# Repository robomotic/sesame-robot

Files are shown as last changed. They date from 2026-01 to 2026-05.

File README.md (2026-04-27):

# The Sesame Robot Project 
___







sesame-cover

<p align="center">
  <a href="https://www.youtube.com/watch?v=NIgoQVQF_Ng">
    tutorial-button
  </a>
  <a href="https://discord.gg/XDXkhQd8bC">
    discord-button
  </a>
</p>

___

**Greetings, from your new best friend.**

Sesame is an accessible Open-Source robotics project based on the ESP32 microcontroller system, with an emphasis on expression and movement. 
This project is designed for makers and engineers of all skill levels! Sesame offers a dynamic platform designed to start working with walking robots. 
To build a sesame robot, you will need basic soldering skills, $50-60 in hardware components, access to a 3D printer, and a basic understanding of Arduino IDE.

This repository contains the CAD design files, STL files, build and wiring guides, and the base/expanded firmware for the ESP32-based controller. 
There is also some included debugging firmware that may be helpful in getting your Sesame up and running.

## ⚡ Fork Notice: Leg & Foot Variations Specialist

**This is a specialized fork repository dedicated to developing and documenting different leg and foot variations for the Sesame robot.**

Explore alternative leg designs optimized for different locomotion characteristics and environmental conditions. All variations are 3D-printable and compatible with the standard Sesame platform. Find the STL files and assembly guides in `hardware/printing/`.

### Leg Variation Types

#### 1. Soft TPU Foot (Dampening)
A compliant, shock-absorbing foot design using flexible TPU material. Perfect for reducing impact forces and improving grip on smooth surfaces.

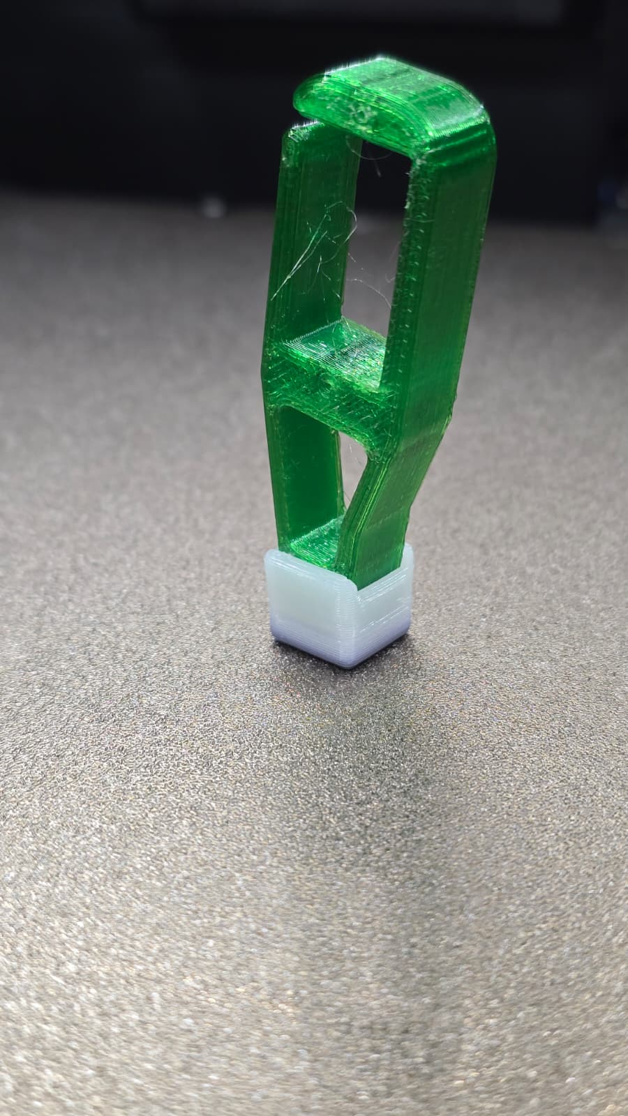
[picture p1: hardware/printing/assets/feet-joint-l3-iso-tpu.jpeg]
soft-tpu-foot


**Characteristics:**
- Excellent vibration dampening
- Enhanced grip on smooth surfaces
- Quieter operation
- Reduced stress on servo joints

#### 2. Shock Suspension with LEGO Integration
An advanced suspension system based on the LEGO 6.5L Soft Spring Grey component (Part #731c08). Provides spring-like shock absorption through mechanical linkage.

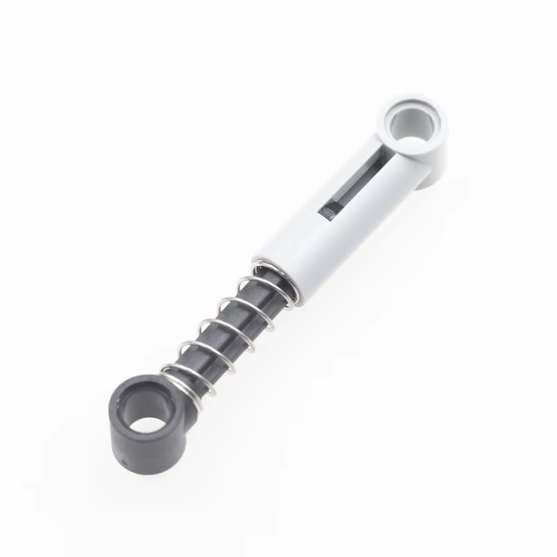
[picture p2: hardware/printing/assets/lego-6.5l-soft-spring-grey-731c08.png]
lego-6.5l-soft-spring


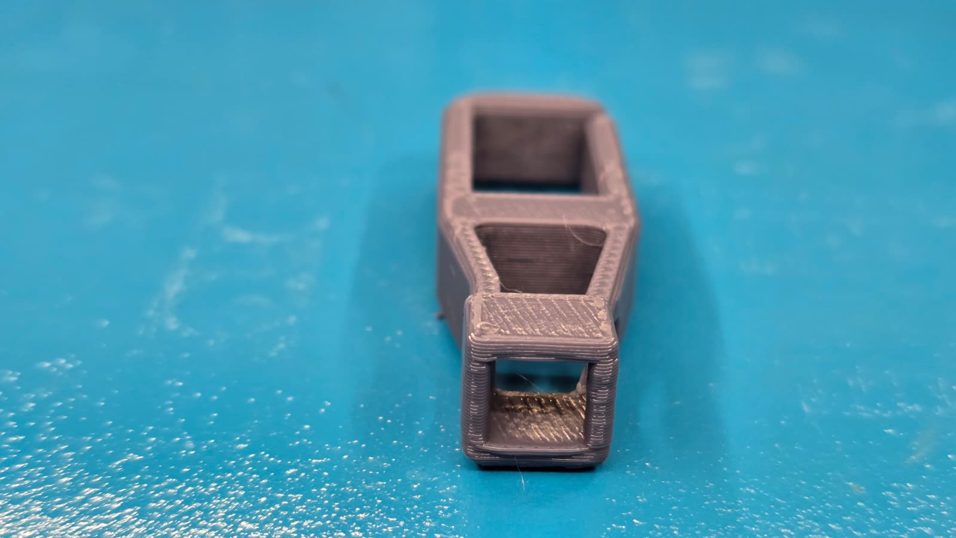
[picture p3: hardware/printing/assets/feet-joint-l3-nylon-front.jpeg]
lego-suspension


**Characteristics:**
- LEGO Part: 731c08 - 6.5L Soft Spring Grey
- Modular suspension design
- LEGO-compatible connectors
- Adjustable stiffness
- Superior obstacle traversal

#### 3. L4 Drilled Shock Harness (Experimental)
A modified version of the original L4 foot joint, drilled to accommodate the LEGO shock absorber spring. This design integrates the suspension directly into the foot structure.

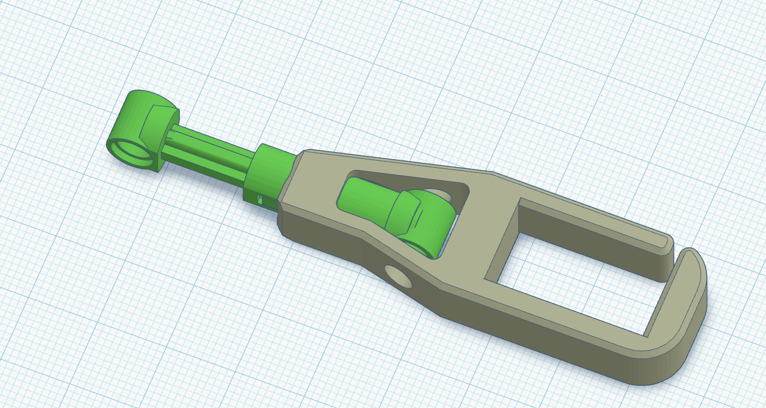
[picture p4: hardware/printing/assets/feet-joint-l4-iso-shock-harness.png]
l4-shock-harness


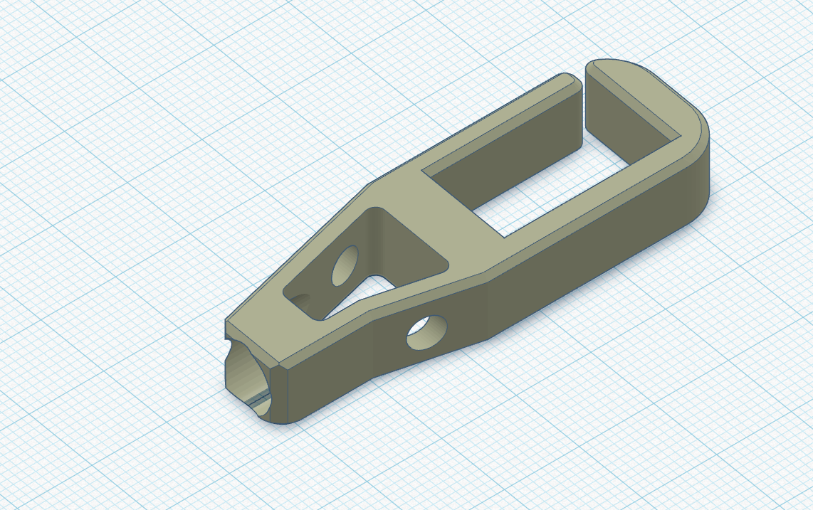
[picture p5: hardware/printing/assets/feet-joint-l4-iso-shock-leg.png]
l4-shock-leg


**Characteristics:**
- Based on original L4 foot joint design
- Direct LEGO spring integration
- More compact form factor
- ⚠️ **Note:** Bottom section requires structural reinforcement - design refinement in progress

---

## Features

*   **Quadruped Design:** Uses 8 servo motors (2 per leg) to achieve roughly 8 total degrees of freedom.
*   **Emotive Display:** Features a 128x64 OLED screen acting as a reactive face that syncs with movement.
*   **Fully Printable:** Designed entirely for 3D printing in PLA with minimal supports.
*   **Network Connectivity:** Connect to your WiFi network for remote control and API access.
*   **ESP-NOW Wireless:** Optional ESP-NOW firmware for sub-5ms latency, peer-to-peer control without WiFi (requires second ESP32 board).
*   **JSON API:** RESTful API for programmatic control from Python, JavaScript, and more.
*   **Conversational Faces:** Expressive emotion library with talk variants for voice assistant projects.
*   **Sesame Studio:** New animation composer software to easily create custom movements.
*   **Sesame Companion App:** Python application for voice control and advanced interactions.
*   **Serial CLI:** Control the robot and trigger animations via a Serial Command Line Interface or the web UI.
*   **Pre-programmed Emotes:** Includes animations for Walking, Waving, Dancing, Pointing, Resting, and more.

## Watch the launch video on YouTube

<a href="https://www.youtube.com/watch?v=1UDsWkcQZhc">thumb-youtube</a>

___

## Getting Started

Follow these steps to build your own Sesame Robot:

### 1. Gather Parts 
Check the **[Bill of Materials (BOM)](hardware/bom/README.md)** for a complete list of required electronics and hardware.
*   Microcontroller: Lolin S2 Mini (recommended for DIY builds), Sesame Distro Board V2 (included in Build Kits, pre-flashed), or ESP32-DevKitC-32E with Distro Board V1 (legacy)
*   Actuators: 8x MG90 Servos
*   Power: 5V 3A source (USB-C PD for S2 Mini and V2 Distro Board, or battery + buck converter; see BOM for the 2× 10440 Li-ion + 2× AAA holder option)

### 2. Print Parts 
Download the STLs and follow the **[Printing Guide](hardware/printing/README.md)**.
*   Designed for PLA
*   Minimal supports required

### 3. Build & Wire 
Follow the **[Build Guide](docs/build-guide/README.md)** and **[Wiring Guide](docs/wiring-guide/README.md)** to assemble the frame and connect the electronics.

### 4. Flash Firmware 
Upload the code from the **[Firmware Directory](firmware/README.md)**.
*   Requires Arduino IDE
*   Configure WiFi AP settings

#### Optional: ESP-NOW Low-Latency Firmware
For sub-5ms control via USB serial (no WiFi needed), flash the ESP-NOW variant instead:
1. Flash **Robot** with `firmware/sesame-firmware-espnow.ino` (ESP32-S3)
2. Flash **Controller** with `software/esp-now/ESP32_C3_Sesame/ESP32_C3_Sesame.ino` (ESP32-C3 Mini, plugged into your computer)
3. Set robot MAC in controller via serial: `SET_ROBOT_MAC <robot_mac>`
4. Send `PING` to verify connection
*See [ESP-NOW docs](software/esp-now/ESP32_C3_Sesame/README.md) for full details.*

### 5. Create Animations 
Use **[Sesame Studio](software/sesame-studio/README.md)** to visually design poses and sequences for your robot.

sesame-wakeup-gif

---

## Software & Firmware

### Sesame Studio
Sesame Studio is a standalone desktop application included in `software/sesame-studio/`. It allows you to:
*   Visually pose the robot using a schematic interface.
*   Generate C++ code for servo angles automatically.
*   Sequence frames into complex animations.

[**> Go to Sesame Studio**](software/sesame-studio/README.md)

### Sesame Simulator
The Sesame Simulator, created by Jay Li, is a Rust-based 3D simulation environment for testing Sesame's movements and kinematics in a virtual space. It features:
*   **Physics-based Simulation:** Test walking and balance without hardware.
*   **Web-based Interface:** Run the simulator directly in your browser.
*   **URDF Integration:** Accurate modeling of Sesame's physical properties.

[**> Go to Sesame Simulator**](https://one-for-all.github.io/sesame-robot-sim/)

### Sesame Companion App
The Sesame Companion App is a Python-based application that enables advanced control and interaction with your robot over your local network. It leverages the new JSON API and network mode features to provide:
*   **Voice Assistant Integration:** Control Sesame with voice commands and see real-time emotional expressions.
*   **Remote Control:** Command your robot from anywhere on your local network.
*   **Face Control:** Change expressions dynamically based on conversation or context.
*   **API Examples:** Reference implementation for building your own integrations.

The Companion App works with robots running the latest firmware with network mode enabled.

[**> Go to Sesame Companion App Repository**](https://github.com/dorianborian/sesame-companion-app)

### ESP-NOW Firmware (Low-Latency Wireless)

An alternative firmware that replaces WiFi-based control with ESP-NOW radio protocol for sub-5ms latency and simpler setup (no access point needed). Controlled via USB serial from any computer or Raspberry Pi.

*   **Extremely low latency** — 1-5 ms round trip vs 20-100 ms over HTTP
*   **No WiFi router needed** — peer-to-peer ESP-NOW radio link
*   **Universal control** — Python, Node.js, shell scripts, or any serial terminal
*   **Bidirectional** — send commands and query status, trims, config
*   **Reserved for future sensors** — protocol includes MPU6050 data slots

**Hardware:** ESP32-S3 (robot) + ESP32-C3 Mini (USB bridge)

[**> Go to ESP-NOW Documentation**](software/esp-now/ESP32_C3_Sesame/README.md)

[**> Quick Debug Reference**](software/esp-now/DEBUG_CHECKS.md)

### Firmware
The ESP32 firmware (`sesame-firmware-main.ino`) handles the kinematics, face display, and WiFi control interface.
*   **Web UI:** Control the robot from your phone via the built-in Access Point.
*   **Custom Faces:** Add your own bitmaps (guide in firmware docs).

[**> Go to Firmware Docs**](firmware/README.md)

---

## Contributing

This robot is a platform for building new features, cosmetics, tools, and ideas. Since the current firmware is a basic implementation, pull requests are very welcome for:
*   Kinematics improvements
*   New animations
*   Improved Web UI/UX
*   Sensor integration (Ultrasonic, Gyro, etc.)

I would also love to see forks of this project with new hardware, software, faces, etc. Be sure to send me a message if you end up building one, and I might feature you on my website or channel!
  
---

## Sesame Complete Build Kit Pre-orders available!
I am excited to announce that, after popular demand, Sesame Complete Build Kits are now available for pre-order! 

That's right, your little robot companion just got even easier to build. Each kit includes all the components you need to build a full Sesame Robot. With the included detailed instructions, guides, and resources, this kit is perfect for both seasoned Makers and beginners. Click the image below to learn more.

<a href="https://www.doriantodd.com/sesame/kit">kits-availible</a>

---

## Credits

A special thanks to **Jason** for his invaluable contributions to 3D printing and design optimization. His expertise and dedication have greatly enhanced the quality and manufacturability of the Sesame robot platform.

---

*Created by [Dorian Todd](https://www.doriantodd.com/). Need help with your Sesame Robot? Send me a message on Discord, my username is "starphee"*

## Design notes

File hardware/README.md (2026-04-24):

# Hardware

All mechanical and electrical source files for the Sesame Robot live here. The hardware stack supports multiple build paths:

- **Hand-wired / Lolin S2 Mini build** for simple protoboard construction (recommended for DIY builds).
- **Custom Sesame Distro Board V2 build** for a professional SMD design with PD and battery support (included in Sesame Build Kits, pre-flashed).
- **Custom Sesame Distro Board V1 build** (legacy) for ESP32-DevKitC-32E stackup (phased out but still supported).

Use the sections below to jump to the files that match the version you are assembling.

## Directory Guide

| Folder | What you will find |
| --- | --- |
| [bom](bom/README.md) | Full bill of materials covering both wiring approaches, plus power budget notes and links back to the build tutorial. Start here to gather every component before printing or soldering. |
| [cad](cad/README.md) | Parametric STEP and Fusion 360 source models for every printed part. Great for remixing joint geometry or adapting the shell—just note the caution about features that may not translate across CAD packages. |
| [pcb](pcb/README.md) | Sesame Distro Board V2 (current) and V1 (legacy) schematics, layout files, Gerber files, BOM, and Pick-and-Place files. Includes ordering instructions for PCBway fabrication and assembly services. |
| [printing](printing/README.md) | Practical PLA print settings, support callouts, and image references for joint orientation and the top cover’s manual supports. |

## Getting Started

1. **Decide on a wiring strategy.** Review the comparison section in [docs/wiring-guide/README.md](../docs/wiring-guide/README.md) to choose between the protoboard and custom PCB routes. The Lolin S2 Mini build is recommended for DIY builders. If you have a Sesame Build Kit, your V2 Distro Board is already pre-flashed and ready to use.
2. **Print the shell and joints.** Follow the presets in [printing/README.md](printing/README.md) to prep the 3D files from `hardware/printing/stl`.
3. **Source electronics.** Use the line-by-line list in [bom/README.md](bom/README.md) and verify your power supply meets the 5V/3A requirement.
4. **Assemble electronics.** Reference either the hand-wiring steps or the appropriate Distro Board guide plus the wiring diagrams in `docs/wiring-guide/`.

> [!TIP]
> Keep photos of your wiring progress. They are invaluable for troubleshooting later and help when sharing build notes with the community.

## Supporting Documents

- [docs/build-guide/README.md](../docs/build-guide/README.md) for end-to-end assembly sequencing.
- [docs/wiring-guide/README.md](../docs/wiring-guide/README.md) for wiring diagrams, safety notes, and packing tips.

Improvements, remixes, and test reports are welcome, file issues or PRs with any updates you discover while building. <3

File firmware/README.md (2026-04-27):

# Sesame Robot Firmware

This document provides technical information on the firmware architecture, control logic, and hardware abstraction layers used in the Sesame Robot.

>[!NOTE]
> The firmware is now organized into a modular structure with a main entry point and specialized header files for bitmaps, movement, and web assets. This makes customization much easier and the codebase cleaner.

## Table of Contents

- [How to Flash the Firmware](#how-to-flash-the-firmware)
- [Network Configuration](#network-configuration--connectivity)
- [API Reference](#api-reference)
  - [Legacy Web Endpoints](#legacy-web-endpoints)
    - [Servo Trims](#servo-trims)
  - [JSON API](#json-api-recommended-for-network-clients)
  - [Python Examples](#python-api-example)
  - [JavaScript Examples](#nodejsjavascript-example)
- [Advanced Integration Examples](#advanced-integration-examples)
  - [Voice Assistant Integration](#voice-assistant-integration)
  - [Home Automation](#home-automation-integration)
- [Servo Calibration & Trims](#servo-calibration--trims)
- [Idle Animation System](#idle-animation-system)
- [Firmware Architecture](#firmware-architecture)
- [Technical Implementation](#technical-implementation-overview)
- [Asset Pipeline & Face Customization](#asset-pipeline--face-customization)
- [Hardware Abstraction Layer](#hardware-abstraction-layer-hal)

## How to Flash the Firmware

> [!NOTE]
> **Sesame Build Kit Users:** Your Distro Board V2 comes pre-flashed with the latest firmware. You only need to flash firmware if you want to customize it or update to a newer version.

### Prerequisites
1. **Arduino IDE** (version 2.0 or higher recommended)
2. **ESP32 Board Support**: Install via Arduino IDE's Board Manager
   - Open Arduino IDE
   - Go to **File → Preferences**
   - Add to "Additional Board Manager URLs": `https://raw.githubusercontent.com/espressif/arduino-esp32/gh-pages/package_esp32_index.json`
   - Go to **Tools → Board → Boards Manager**
   - Search for "ESP32" and install "ESP32 by Espressif Systems" (v2.0.0 or higher)
3. **Required Libraries** (install via Library Manager):
  - `ESP32Servo` **v3.0.9** (recommended)
   - `Adafruit SSD1306`
   - `Adafruit GFX Library`

> [!IMPORTANT]
> Use **ESP32Servo v3.0.9** for this project. Newer releases currently have a known issue where writing to one servo can affect multiple channels ([madhephaestus/ESP32Servo#103](https://github.com/madhephaestus/ESP32Servo/issues/103)).

### Flashing Steps
1. **Connect your board** via USB to your computer
2. **Open the firmware**:
   - Open [sesame-firmware-main.ino](sesame-firmware-main.ino) in Arduino IDE
   - Make sure you have it in a folder with the same name.
   - Also include all of the .h header files.
3. **Select your board**:
   - Go to **Tools → Board**
   - For Lolin S2 Mini: Select "LOLIN S2 Mini"
   - For Sesame Distro Board V1: Select "ESP32 Dev Module"
   - For Sesame Distro Board V2: Select "ESP32S3 Dev Module"
4. **Configure board settings**:
   - **For Lolin S2 Mini**:
     - **Upload Speed**: 921600
     - **USB CDC On Boot**: "Enabled"
     - **Partition Scheme**: "Default 4MB with spiffs"
   - **For Distro Board V2 (ESP32-S3)**:
     - **USB CDC On Boot**: "Enabled" (Required for Serial Monitor)
     - **Flash Mode**: "QIO 80MHz"
     - **Partition Scheme**: "Default 4MB with spiffs"
5. **Select the correct port**:
   - Go to **Tools → Port** and select your ESP32's COM port
6. **Choose your board configuration** in the code:
   - Open [sesame-firmware-main.ino](sesame-firmware-main.ino)
   - Find the pin configuration section (around line 55-65)
   - **If you built with the Lolin S2 Mini:** Uncomment the S2 Mini `servoPins` array and `I2C_SDA`/`I2C_SCL` defines. Comment out the Distro Board section.
   - **If you built with the Distro Board V1 or V2 and ESP32-DevKitC-32E:** Uncomment the Distro Board `servoPins` array and `I2C_SDA`/`I2C_SCL` defines. Comment out the S2 Mini section. (V1 and V2 use the same pin configuration)
7. **(Optional) Configure network mode**:
   - If you want the robot to connect to your WiFi network (for API access and remote control), edit the network configuration section (around line 17-22):
   ```cpp
   #define NETWORK_SSID "YourNetworkName"  // Your WiFi network name
   #define NETWORK_PASS "YourPassword"     // Your WiFi password
   #define ENABLE_NETWORK_MODE true        // Set to true to enable
   ```
   - Leave `ENABLE_NETWORK_MODE false` to use Access Point mode only
8. **Upload the firmware**:
   - Click the **Upload** button (→) in Arduino IDE
   - Wait for compilation and upload to complete
9. **Test the connection**:
   - Open Serial Monitor (**Tools → Serial Monitor**, set baud rate to 115200)
   - Reset the board - you should see startup messages and network information
   - The serial monitor provides individual motor control for testing and troubleshooting
   - **If using AP mode only**: Connect to the "Sesame-Controller-BETA" WiFi network (password: `12345678`) and navigate to any website
   - **If using network mode**: Look for the "Connected to network!" message in Serial Monitor, then access via `http://sesame-robot.local` or the displayed IP address

### Troubleshooting
- **Linux USB Permissions**: If your port isn't showing up or you get "Permission Denied", you likely need to add your user to the `dialout` group: `sudo usermod -a -G dialout $USER`. Log out and back in for changes to take effect.
- **Upload fails**: Try holding the BOOT button while uploading, or try a different USB cable. For S3-based boards, the "USB CDC On Boot" setting is critical for finding the port after a reset.
- **Port not found**: Install the appropriate USB drivers (CP210x for S2 Mini, CH340 for some ESP32 boards). Windows 10/11 usually includes these.
- **Robot not moving**: Check power supply and servo connections; increase `motorCurrentDelay` in web settings if brownouts occur
- **Can't connect to network**: 
  - Verify `ENABLE_NETWORK_MODE` is set to `true` and SSID/password are correct
  - Check Serial Monitor for connection status - look for "Connected to network!" or error messages
  - Ensure your WiFi network is 2.4GHz (ESP32 does not support 5GHz)
  - Try increasing the connection timeout in the code (currently 10 seconds / 20 attempts)
- **mDNS hostname not resolving**:
  - On Windows, install [Bonjour Print Services](https://support.apple.com/kb/DL999)
  - On Linux, ensure `avahi-daemon` is installed and running
  - Try accessing via IP address instead (check Serial Monitor for the assigned IP)
  - Some routers block mDNS traffic - check router settings or use IP address
- **API commands not working**:
  - Ensure you're sending POST requests to `/api/command` (not GET)
  - Verify `Content-Type: application/json` header is set
  - Check Serial Monitor for error messages and parsed command output
  - Test with a simple cURL command first to verify connectivity

## Firmware Architecture

The firmware is split into several key files to keep the logic organized and assets easy to manage:

- **[sesame-firmware-main.ino](sesame-firmware-main.ino)**: The main entry point containing the `setup()`, `loop()`, core system logic, network configuration, and API endpoints.
- **[face-bitmaps.h](face-bitmaps.h)**: A dedicated header for OLED face macros and raw bitmap data. Now includes extensive conversational faces for voice assistant integration.
- **[movement-sequences.h](movement-sequences.h)**: Definitions for all procedural movement and pose animations.
- **[captive-portal.h](captive-portal.h)**: Contains the HTML, CSS, and JS for the web-based remote control interface.

## Servo Calibration & Trims

The firmware includes a built-in servo trim system to compensate for mechanical misalignment. This is essential because servo center positions may vary between units.

### Using the Web UI
1. **Access the Trims panel**: Open the web interface and tap **Trims** in the System section
2. **Adjust each servo**: Use the `+` and `-` buttons for each motor (L1-L4, R1-R4)
3. **Real-time feedback**: The robot moves immediately when you adjust a trim
4. **Visual indicators**: Green = positive offset, Red = negative offset, Theme color = zero
5. **Save**: Values are applied immediately; use "Save Trims" to confirm, or "Reset" to zero all values

### How Trims Work
- Trims are stored as `int8_t servoSubtrim[8]` offsets (degrees) applied to every servo command
- The firmware tracks each servo's target angle and re-applies all trims when any trim changes
- All poses, movements, and manual controls automatically include the trim offset
- Range: **-90 to +90 degrees** per servo

### NVS Persistence
The firmware can save trim values to ESP32 non-volatile storage (NVS):
```cpp
#define SAVE_TRIMS true  // Set to true to persist trims across reboots
```
When `SAVE_TRIMS` is `false` (default for testing), trims reset to zero on each boot. Set to `true` for production use.

### Serial CLI Commands
```
subtrim              - Display current trim values
subtrim <motor> <v>  - Set trim for motor 0-7 to value -90..+90
subtrim save         - Save trims to NVS
subtrim reset        - Zero all trims and save to NVS
```

## Technical Implementation Overview

The firmware is built on the Arduino-ESP32 framework. Currently the firmware is running on a single-core event loop, and hardware-based PWM timers for precise motor control.

### PWM & Servo Kinematics
- **Timer Allocation**: The firmware uses `ESP32PWM::allocateTimer(n)` to reserve hardware timers 0-3. This prevents conflicts with other peripherals and ensuring high-resolution PWM signals (50Hz frequency). Due to the limited number of timers, you may experience network errors upon adding additional devices or calls to the firmware. For example, in a modded version of the robot, I tried adding two ESCs and their servo controll to the code, and the CPU ran out of internal timers and caused the captive portal to die. If you are experiencing network errors with your custom firmware, check the timer allocation.
- **Pulse Width Mapping**: Leg servos are mapped from degrees (0-180) to microseconds (732us to 2929us). This range is set to the maximum travel on most hobby servos with a 180 degree limit, but can be edited in the `servos[i].attach()` calls. If you are using motors with a larger range of motion, like 270 degree servos, you need to set the PWM mapping to a different length of microseconds. For 270 degree servos specifically I found (833us to 2167us) works.
- **Staggered Activation**: To prevent VCC rail collapse (brownout) caused by simultaneous inductive loads, the `setServoAngle` helper introduces a mandatory `motorCurrentDelay` (default 20ms) between sequential pulses. This delay should be tweaked to your power setup. If you have a strong dedicated power supply you can try setting it to zero. It can also be changed while running through the AP controller settings menu.

### Communication & Networking Stack
- **Dual-Mode WiFi**: The ESP32 can simultaneously operate in both Access Point mode (for direct connections) and Station mode (connected to an existing network) using `WiFi.mode(WIFI_AP_STA)`.
- **SoftAP & Captive Portal**: The ESP32 initializes an Access Point using `WiFi.softAP()`. A `DNSServer` listens on UDP Port 53, using a wildcard "*" redirect to map all DNS queries to the internal gateway (`192.168.4.1`).
- **mDNS Service Discovery**: The firmware broadcasts `sesame-robot.local` via Multicast DNS (mDNS) using the `ESPmDNS` library, allowing network discovery without hardcoded IP addresses.
- **RESTful API Surface**: The `WebServer` handles both legacy URL-parameter endpoints and modern JSON-based API:
  - `/cmd?go=[dir]`: Legacy movement control
  - `/cmd?pose=[name]`: Legacy pose triggers
  - `/api/status`: JSON status endpoint (GET)
  - `/api/command`: JSON command endpoint (POST) - supports face-only updates and combined face+movement commands
  - `/getSettings` / `/setSettings`: Parameter configuration
  - `/getSubtrim` / `/setSubtrim` / `/resetSubtrim`: Servo subtrim management
- **Face-Only Command Support**: The `/api/command` endpoint intelligently detects face-only requests (no `command` field) and updates the display without triggering movement animations.
- **Non-Blocking Control Flow**: Instead of `delay()`, the firmware uses a custom `pressingCheck(String cmd, int ms)` function. This function polls `server.handleClient()` and `dnsServer.processNextRequest()` during animation frames, allowing for real-time interruptibility (e.g., immediate stop on button release). This pressingCheck protocol can be used for motion commands like walking to play each motion only when the button is held.

### Display & Graphics Subsystem
- **I2C Bus Hardware**: Utilizes the ESP32's hardware I2C controller at 400kHz (Fast Mode) for minimal latency when pushing full-frame buffers to the SSD1306 display.
- **Memory Management (`PROGMEM`)**: Large 128x64 bitmap arrays (1024 bytes per frame) are stored in Flash memory using the `PROGMEM` attribute.
- **Macro-Based Asset Management**: The firmware uses a `FACE_LIST` macro in [face-bitmaps.h](face-bitmaps.h) to automatically register and handle new faces, reducing the boilerplate required when adding animations.
- **Rendering Pipeline**: The `updateAnimatedFace()` function manages frame rates and sequence looping outside of the main movement logic to ensure smooth visual feedback even during complex movements.
- **Dynamic WiFi Info Overlay**: The `updateWifiInfoScroll()` function composites scrolling connection information over the face bitmap during the first 30 seconds of operation (before first input), drawing the face as background with a black bar and white text overlay for readability.
- **Idle Animation System**: Implements realistic idle behavior with randomized blinking (including double-blinks) and boomerang face animations, triggered automatically when no input is detected.

### Web Control Interface
The web interface ([captive-portal.h](captive-portal.h)) provides a responsive mobile-first controller:
- **Movement D-Pad**: Hold-to-move directional controls with immediate stop on release
- **Pose Grid**: One-tap pose triggers for animations (wave, dance, swim, etc.)
- **Manual Motor Control**: Per-servo angle sliders for fine positioning
- **Servo Trims**: Full-screen trim panel with +/- buttons for each servo (L1-L4, R1-R4)
  - Real-time servo movement on each trim adjustment
  - Values persist across reboots via ESP32 NVS (toggle with `#define SAVE_TRIMS`)
  - Trims are applied as offsets to all poses and movements automatically
  - Range: -90 to +90 degrees per servo
- **Gamepad Support**: Automatic detection and polling of USB/Bluetooth gamepads
- **Theme Customization**: Color picker with preset themes and custom color support

## Prerequisites & Development Environment

- **Board Support**: ESP32 by Espressif Systems (v2.0.0+ recommended). Lolin S2 Mini and ESP32-WROOM32 DevKitC are best supported.
- **Libraries**:
  - `ESP32Servo` **v3.0.9**: Low-level PWM timer management. (Pinned due to known multi-servo command leak in newer versions: [madhephaestus/ESP32Servo#103](https://github.com/madhephaestus/ESP32Servo/issues/103))
  - `Adafruit_SSD1306` & `Adafruit_GFX`: Buffer-based OLED rendering.
  - `ESPmDNS`: mDNS service discovery (included with ESP32 board support).
  - `DNSServer`: Captive portal DNS redirection (included with ESP32 board support).
  - `WebServer`: HTTP server implementation (included with ESP32 board support).
- **Tooling**: Arduino IDE 2.0+ recommended.

## Network Configuration & Connectivity

The firmware now supports **dual-mode WiFi operation**, allowing the robot to simultaneously act as an Access Point (for direct connections) and connect to your existing WiFi network (for integration with other devices and remote control).

### Access Point Mode (Default)
By default, the robot creates its own WiFi network:
- **SSID**: `Sesame-Controller-BETA`
- **Password**: `12345678` (Some devices may require you to change this if the default isn't connecting)
- **IP Address**: `192.168.4.1`

Connect to this network and navigate to any website to access the captive portal control interface. If you're having trouble connecting, try changing the password to something custom in the code's `#define AP_PASS` section.

### Network Mode (Optional)
To connect the robot to your home or office WiFi network:

1. **Enable Network Mode** in [sesame-firmware-main.ino](sesame-firmware-main.ino):
   ```cpp
   #define NETWORK_SSID "YourNetworkName"  // Your WiFi network name
   #define NETWORK_PASS "YourPassword"     // Your WiFi password
   #define ENABLE_NETWORK_MODE true        // Set to true to enable
   ```

2. **Flash the updated firmware** to your robot.

3. **Access via multiple methods**:
   - **mDNS Hostname**: `http://sesame-robot.local` (works on most devices)
   - **Network IP**: Check Serial Monitor at 115200 baud for the assigned IP address
   - **Still accessible via AP**: The robot maintains its Access Point even when connected to your network

### mDNS Discovery
The firmware includes an mDNS responder that broadcasts the hostname `sesame-robot.local` on your local network. This allows you to access the robot without knowing its IP address:

```bash
# Access from browser
http://sesame-robot.local

# Ping test
ping sesame-robot.local
```

**Note**: mDNS works natively on:
- macOS and iOS devices
- Linux with Avahi installed
- Windows 10+ (may require Bonjour service)

### Security Considerations

The firmware is designed for local network use and does not include authentication by default. When enabling network mode:

- **Local Network Only**: The robot responds to requests from any device on your network. Do not expose it to the internet without proper security measures.
- **No HTTPS**: Communication is unencrypted HTTP. Avoid transmitting sensitive data through the robot's API.
- **Access Point Password**: The default AP password is `12345678`. For production use, change `AP_PASS` in the firmware to a stronger password.
- **Trusted Networks**: Only connect your robot to trusted WiFi networks.

For enhanced security:
1. Change the default AP password to a strong, unique password
2. Use network segmentation (IoT VLAN) to isolate the robot from critical devices
3. Implement firewall rules to restrict access to specific IP addresses
4. Consider adding authentication headers in a custom firmware fork for production deployments

### WiFi Information Display
The robot's OLED screen now features an intelligent WiFi info system:
- **First 30 seconds**: If no input is received, WiFi connection information scrolls across the top of the display
- **After first input**: WiFi info disappears to show only faces
- **Dual-mode info**: When connected to both AP and network, displays both connection details

The scrolling text includes:
- Access Point SSID and IP
- Network name and IP (if connected)
- mDNS hostname
- Captive portal instructions

## API Reference

The firmware exposes both legacy web endpoints and a modern JSON-based API for programmatic control.

### Legacy Web Endpoints

These endpoints use URL parameters and are primarily used by the web interface:

#### Movement Control
```http
GET /cmd?go=forward
GET /cmd?go=backward
GET /cmd?go=left
GET /cmd?go=right
GET /cmd?stop
```

#### Pose Control
```http
GET /cmd?pose=wave
GET /cmd?pose=dance
GET /cmd?pose=rest
GET /cmd?pose=stand
# ... (see movement-sequences.h for all available poses)
```

#### Individual Motor Control
```http
GET /cmd?motor=1&value=90
# motor: 1-8 (motor number)
# value: 0-180 (angle in degrees)
```

#### Settings Management
```http
GET /getSettings
# Returns: {"frameDelay":100,"walkCycles":10,"motorCurrentDelay":20,"faceFps":8}

GET /setSettings?frameDelay=120&walkCycles=15&motorCurrentDelay=25&faceFps=10
```

#### Servo Trims
```http
GET /getSubtrim
# Returns: {"subtrim":[0,0,0,0,0,0,0,0]}

GET /setSubtrim?motor=1&value=5
# Sets servo 1 trim to +5 degrees (range: -90 to +90)

GET /resetSubtrim
# Resets all servo trims to 0
```

### JSON API (Recommended for Network Clients)

The JSON API is designed for programmatic control from external devices, Python scripts, and IoT integrations.

#### Get Robot Status
```http
GET /api/status
```

**Response:**
```json
{
  "currentCommand": "forward",
  "currentFace": "walk",
  "networkConnected": true,
  "apIP": "192.168.4.1",
  "networkIP": "192.168.1.100"
}
```

#### Send Commands
```http
POST /api/command
Content-Type: application/json

{
  "command": "forward",
  "face": "walk"
}
```

**Response:**
```json
{
  "status": "ok",
  "message": "Command executed"
}
```

#### Face-Only Updates
Send a face change without triggering movement:

```http
POST /api/command
Content-Type: application/json

{
  "face": "happy"
}
```

**Response:**
```json
{
  "status": "ok",
  "message": "Face updated"
}
```

#### Stop Command
```http
POST /api/command
Content-Type: application/json

{
  "command": "stop"
}
```

### Available Commands

**Movement Commands:**
- `forward`, `backward`, `left`, `right` - Continuous movement (loops until stopped)
- `stop` - Immediately stop current movement

**Pose Commands (one-shot animations):**
- `rest`, `stand`, `wave`, `dance`, `swim`, `point`
- `pushup`, `bow`, `cute`, `freaky`, `worm`, `shake`
- `shrug`, `dead`, `crab`

**Available Faces:**
- Movement faces: `walk`, `rest`, `stand`, `dance`, `wave`, etc.
- Conversational faces: `happy`, `sad`, `angry`, `surprised`, `sleepy`, `love`, `excited`, `confused`, `thinking`
- Talk variants: `talk_happy`, `talk_sad`, `talk_angry`, etc.
- Special: `idle`, `idle_blink`, `default`

### Python API Example

```python
import requests
import time

# Robot IP or hostname
robot_url = "http://sesame-robot.local"

# Get status
response = requests.get(f"{robot_url}/api/status")
status = response.json()
print(f"Current face: {status['currentFace']}")

# Make robot wave and show happy face
requests.post(f"{robot_url}/api/command", json={
    "command": "wave",
    "face": "happy"
})

time.sleep(3)

# Just change face without moving
requests.post(f"{robot_url}/api/command", json={
    "face": "excited"
})

# Stop movement
requests.post(f"{robot_url}/api/command", json={
    "command": "stop"
})
```

### cURL Examples

```bash
# Get robot status
curl http://sesame-robot.local/api/status

# Make robot dance
curl -X POST http://sesame-robot.local/api/command \
  -H "Content-Type: application/json" \
  -d '{"command":"dance","face":"dance"}'

# Change face only
curl -X POST http://sesame-robot.local/api/command \
  -H "Content-Type: application/json" \
  -d '{"face":"happy"}'

# Stop movement
curl -X POST http://sesame-robot.local/api/command \
  -H "Content-Type: application/json" \
  -d '{"command":"stop"}'
```

### Node.js/JavaScript Example

```javascript
const robotURL = 'http://sesame-robot.local';

// Get status
fetch(`${robotURL}/api/status`)
  .then(res => res.json())
  .then(data => console.log('Robot status:', data));

// Send command
fetch(`${robotURL}/api/command`, {
  method: 'POST',
  headers: {'Content-Type': 'application/json'},
  body: JSON.stringify({
    command: 'wave',
    face: 'happy'
  })
})
.then(res => res.json())
.then(data => console.log('Response:', data));

// Face-only update
fetch(`${robotURL}/api/command`, {
  method: 'POST',
  headers: {'Content-Type': 'application/json'},
  body: JSON.stringify({face: 'surprised'})
})
.then(res => res.json())
.then(data => console.log('Response:', data));
```

## Advanced Integration Examples

### Voice Assistant Integration

The combination of conversational faces, the JSON API, and network mode makes the Sesame Robot perfect for voice assistant projects. Here's an example using Python with speech recognition:

```python
import requests
import speech_recognition as sr
from textblob import TextBlob
import time

robot_url = "http://sesame-robot.local"

def analyze_sentiment(text):
    """Analyze sentiment and return appropriate face"""
    blob = TextBlob(text)
    polarity = blob.sentiment.polarity
    
    if polarity > 0.5:
        return "excited"
    elif polarity > 0.2:
        return "happy"
    elif polarity < -0.5:
        return "angry"
    elif polarity < -0.2:
        return "sad"
    else:
        return "thinking"

def set_robot_face(face, talking=False):
    """Update robot's face expression"""
    if talking:
        face = f"talk_{face}"
    
    requests.post(f"{robot_url}/api/command", json={"face": face})

# Initialize speech recognition
recognizer = sr.Recognizer()

while True:
    with sr.Microphone() as source:
        print("Listening...")
        set_robot_face("idle")
        
        try:
            audio = recognizer.listen(source, timeout=5)
            set_robot_face("thinking")
            
            text = recognizer.recognize_google(audio)
            print(f"You said: {text}")
            
            # Determine emotion and show talking face
            emotion = analyze_sentiment(text)
            set_robot_face(emotion, talking=True)
            
            # Process command...
            time.sleep(2)
            
            # Return to neutral
            set_robot_face(emotion, talking=False)
            
        except sr.WaitTimeoutError:
            set_robot_face("sleepy")
        except sr.UnknownValueError:
            set_robot_face("confused")
```

### Home Automation Integration

Integrate with Home Assistant or other home automation platforms:

```python
# Home Assistant automation example
import requests

def robot_notification(message_type):
    """Display robot emotion based on notification type"""
    robot_url = "http://sesame-robot.local"
    
    emotion_map = {
        "doorbell": "surprised",
        "alarm": "angry",
        "reminder": "thinking",
        "success": "happy",
        "error": "sad"
    }
    
    face = emotion_map.get(message_type, "default")
    requests.post(f"{robot_url}/api/command", json={"face": face})
    
    # Optional: add movement
    if message_type == "doorbell":
        requests.post(f"{robot_url}/api/command", json={
            "command": "wave",
            "face": "happy"
        })
```

### WebSocket Streaming (Advanced)

For real-time control with minimal latency, you can poll the status endpoint or implement a simple state machine:

```javascript
// React/Vue.js real-time robot control
class RobotController {
  constructor(robotURL) {
    this.url = robotURL;
    this.currentFace = 'default';
  }
  
  async updateEmotion(emotion, isSpeaking) {
    const face = isSpeaking ? `talk_${emotion}` : emotion;
    
    if (face !== this.currentFace) {
      await fetch(`${this.url}/api/command`, {
        method: 'POST',
        headers: {'Content-Type': 'application/json'},
        body: JSON.stringify({face})
      });
      
      this.currentFace = face;
    }
  }
  
  async getStatus() {
    const res = await fetch(`${this.url}/api/status`);
    return await res.json();
  }
  
  async performAction(action, emotion = null) {
    const payload = {command: action};
    if (emotion) payload.face = emotion;
    
    await fetch(`${this.url}/api/command`, {
      method: 'POST',
      headers: {'Content-Type': 'application/json'},
      body: JSON.stringify(payload)
    });
  }
}

// Usage
const robot = new RobotController('http://sesame-robot.local');

// Set emotion without moving
await robot.updateEmotion('happy', false);

// Set talking face
await robot.updateEmotion('excited', true);

// Perform action with face
await robot.performAction('dance', 'excited');

// Check status
const status = await robot.getStatus();
console.log(`Robot is ${status.currentFace} and doing ${status.currentCommand}`);
```

## Idle Animation System

The firmware includes an intelligent idle animation system that activates automatically:

### Behavior
- **Activation**: When the robot has received no commands for a period, it enters idle mode
- **Idle Face**: Displays a gentle "breathing" animation using the `idle` face in `FACE_ANIM_BOOMERANG` mode
- **Blinking**: Randomly triggers blink animations (3-7 second intervals)
- **Double Blinks**: 30% chance of a double blink for realistic behavior
- **Exit**: Any movement command or input immediately exits idle mode

### Technical Implementation
The idle system uses:
- `enterIdle()` - Activates idle face with boomerang animation
- `exitIdle()` - Returns to normal operation
- `updateIdleBlink()` - Manages random blink timing and double-blink logic
- `scheduleNextIdleBlink()` - Randomizes blink intervals for natural appearance

To customize idle behavior, modify the timing values in [sesame-firmware-main.ino](sesame-firmware-main.ino):
```cpp
scheduleNextIdleBlink(3000, 7000);  // Min and max ms between blinks
```

## Asset Pipeline & Face Customization

The firmware includes an intelligent idle animation system that activates automatically:

### Behavior
- **Activation**: When the robot has received no commands for a period, it enters idle mode
- **Idle Face**: Displays a gentle "breathing" animation using the `idle` face in `FACE_ANIM_BOOMERANG` mode
- **Blinking**: Randomly triggers blink animations (3-7 second intervals)
- **Double Blinks**: 30% chance of a double blink for realistic behavior
- **Exit**: Any movement command or input immediately exits idle mode

### Technical Implementation
The idle system uses:
- `enterIdle()` - Activates idle face with boomerang animation
- `exitIdle()` - Returns to normal operation
- `updateIdleBlink()` - Manages random blink timing and double-blink logic
- `scheduleNextIdleBlink()` - Randomizes blink intervals for natural appearance

To customize idle behavior, modify the timing values in [sesame-firmware-main.ino](sesame-firmware-main.ino):
```cpp
scheduleNextIdleBlink(3000, 7000);  // Min and max ms between blinks
```

## Hardware Abstraction Layer (HAL)

The firmware abstracts pin definitions via the `servoPins` array. The default configuration is optimized for the **Sesame Distro Board V1/V2** and **Lolin S2 Mini**, but is easily portable to any ESP32 with WiFi capability (e.g., S3, C3, or DevKit V1).

### Pin Configuration Tables

#### Lolin S2 Mini (ESP32-S2)

| Motor/Component | Array Index | GPIO Pin | Notes |
|---|---|---|---|
| Motor 0 | 0 | 1 | R1 |
| Motor 1 | 1 | 2 | R2 |
| Motor 2 | 2 | 4 | L1 |
| Motor 3 | 3 | 6 | L2 |
| Motor 4 | 4 | 8 | R4 |
| Motor 5 | 5 | 10 | R3 |
| Motor 6 | 6 | 13 | L3 |
| Motor 7 | 7 | 14 | L4 |
| **I2C SDA** | - | **33** | SSD1306 Data (Hardware I2C) |
| **I2C SCL** | - | **35** | SSD1306 Clock (Hardware I2C) |

#### Sesame Distro Board V1 & V2 (ESP32-WROOM32)

> [!NOTE]
> Both V1 and V2 Distro Boards use the same pin configuration.

| Motor/Component | Array Index | GPIO Pin | Notes |
|---|---|---|---|
| Motor 0 | 0 | 15 | R1 |
| Motor 1 | 1 | 2 | R2 |
| Motor 2 | 2 | 23 | L1 |
| Motor 3 | 3 | 19 | L2 |
| Motor 4 | 4 | 4 | R4 |
| Motor 5 | 5 | 16 | R3 |
| Motor 6 | 6 | 17 | L3 |
| Motor 7 | 7 | 18 | L4 |
| **I2C SDA** | - | **21** | SSD1306 Data (Hardware I2C) |
| **I2C SCL** | - | **22** | SSD1306 Clock (Hardware I2C) |

### Porting to Other ESP32 Variants

To port this to a different ESP32 variant, modify the `servoPins` and `I2C_` defines in the header of [sesame-firmware-main.ino](sesame-firmware-main.ino). Ensure the chosen pins are PWM-capable and not "input-only".

## Asset Pipeline & Face Customization

To maintain a clean main source file and optimize performance, face bitmaps are decoupled from the primary logic. Faces are managed in [face-bitmaps.h](face-bitmaps.h) using a "Single Source of Truth" macro system.

### Face Library

The firmware includes an extensive library of faces organized into three categories:

#### Movement Faces
Synchronized with physical poses and animations:
- `walk`, `rest`, `stand`, `swim`, `dance`, `wave`, `point`
- `pushup`, `bow`, `cute`, `freaky`, `worm`, `shake`, `shrug`
- `dead`, `crab`, `idle`, `idle_blink`

#### Conversational Faces
Designed for expressive communication and voice assistant integration:
- **Base emotions**: `happy`, `sad`, `angry`, `surprised`, `sleepy`, `love`, `excited`, `confused`, `thinking`
- **Talk variants**: `talk_happy`, `talk_sad`, `talk_angry`, `talk_surprised`, `talk_sleepy`, `talk_love`, `talk_excited`, `talk_confused`, `talk_thinking`

The "talk_" variants feature open mouths for lip-sync and animated speech. These faces are perfect for:
- Voice assistant projects (Alexa, Google Assistant, custom TTS)
- Chatbot interfaces controlled via the JSON API
- Interactive storytelling and educational applications
- Remote-controlled performances

#### Special Faces
- `default` - The startup/fallback face
- `idle` - Gentle breathing animation for idle state
- `idle_blink` - Blink animation triggered randomly during idle

### Adding Custom Faces

### Workflow:
1.  **Image Creation**: Find faces using Kaomoji or [Emojicombos](https://emojicombos.com/kaomoji). Create a `128x64` image in a tool like [jsPaint](https://jspaint.app/).
2.  **Bitmap Conversion**: Use [image2cpp](https://javl.github.io/image2cpp/) with `Horizontal` scaling, `128x64` resolution, and `Arduino Code` output.
3.  **Registration**:
    -   Add your face name to the `FACE_LIST` macro in [face-bitmaps.h](face-bitmaps.h).
    -   Paste the generated C array into [face-bitmaps.h](face-bitmaps.h) right after the last bitmap in the list.
    -   (Optional) For animations, add numbered suffixes (e.g., `_1`, `_2`) and register the FPS in the `faceFpsEntries` in [sesame-firmware-main.ino](sesame-firmware-main.ino).

### Animating Faces
For an animation to be recognized by the `MAKE_FACE_FRAMES` macro, your array names in [face-bitmaps.h](face-bitmaps.h) must follow a strict naming convention:
- **Root Frame**: `epd_bitmap_myface` (This is required and acts as frame 0).
- **Subsequent Frames**: `epd_bitmap_myface_1`, `epd_bitmap_myface_2`, etc.
- **Limit**: The default system supports up to 6 frames per face (Root + 5 numbered frames).
- **Animation Modes**: Animations can be configured to play as a `LOOP` (restarts at frame 0), `ONCE` (stops on the final frame), or `BOOMERANG` (plays forward then reverses). These modes are typically defined in [movement-sequences.h](movement-sequences.h) when triggerring a pose.

### Macro System
The `FACE_LIST` macro uses X-Macros to automatically generate variable declarations and registration objects:
```cpp
#define FACE_LIST \
    X(walk) \
    X(rest) \
    X(my_new_face) // Just add this line!
```
This eliminates the need to manually update multiple switch statements or arrays when adding new assets.

## Execution & Deployment

1.  **Toolchain**: Configure your IDE for `ESP32 Dev Module` or `Lolin S2 Mini`.
2.  **Calibration**: Use the Serial Monitor (115200) to send manual step commands (e.g., `rn wf`).
3.  **Power Management**: If the robot brownouts during movement, increase `motorCurrentDelay` in the web settings to further stagger servo bursts.

## ESP-NOW Firmware (Low-Latency Wireless)

An alternative firmware variant that replaces WiFi-based HTTP control with direct ESP-NOW radio communication. This version achieves sub-5ms latency and eliminates the need for an access point or WiFi router.

### Why Switch to ESP-NOW?

| Feature | WiFi Firmware (`sesame-firmware-main.ino`) | ESP-NOW Firmware (`sesame-firmware-espnow.ino`) |
|---|---|---|
| Control method | WiFi AP + HTTP server | ESP-NOW radio binary protocol |
| Latency | 20–100 ms (HTTP overhead) | 1–5 ms round-trip |
| Network setup | Requires AP connection, captive portal | Peer-to-peer, zero configuration |
| Interface | Web UI on phone/laptop | Serial/USB from computer or Raspberry Pi |
| Power consumption | Higher (WiFi AP active) | Lower (radio only when transmitting) |
| Reliability | TCP/IP stack, reconnection delays | Simple UDP-like packets, immediate |
| Sensor data streaming | Polling via HTTP requests | Can push sensor data asynchronously (future) |

### Hardware Setup

**You need two ESP32 boards:**
1. **Robot:** ESP32-S3 with Sesame Distro Board (flashed with `sesame-firmware-espnow.ino`)
2. **Controller:** ESP32-C3 Mini (flashed with `ESP32_C3_Sesame.ino`) connected to your computer via USB

The two boards communicate wirelessly — no wiring needed. The controller acts as a USB serial bridge, converting text commands from your computer into ESP-NOW binary packets for the robot.

### Getting Started

#### 1. Flash the Robot (ESP32-S3)

1. Open `firmware/sesame-firmware-espnow.ino` in Arduino IDE
2. Board: **ESP32S3 Dev Module**
3. Install libraries: `ESP32Servo` v3.0.9, `Adafruit SSD1306`, `Adafruit GFX`
4. Upload
5. Open Serial Monitor (115200 baud) and copy the MAC address:
   ```
   === Sesame Robot (ESP-NOW) ===
   MAC Address: DC:54:75:C8:43:00
   ```

#### 2. Flash the Controller (ESP32-C3 Mini)

1. Open `software/esp-now/ESP32_C3_Sesame/ESP32_C3_Sesame.ino` in Arduino IDE
2. Board: **ESP32C3 Dev Module**
3. Upload
4. Serial Monitor at 115200 baud
5. Tell the controller the robot's MAC:
   ```
   SET_ROBOT_MAC DC:54:75:C8:43:00
   ```
   This is saved to flash — run it once.

#### 3. Test

```
PING
```
Should respond:
```
PONG rtt=1.23ms
```

```
CMD wave
```
Robot waves.

**That's it.** Full command reference: `software/esp-now/ESP32_C3_Sesame/README.md`

### WiFi Channel Configuration

Both boards must use the same ESP-NOW channel (1–13). Default is channel 1.

**To avoid interference with your WiFi router:**
- If router uses channel 1 → set ESP-NOW to 6 or 11
- If router uses channel 6 → set ESP-NOW to 1 or 11
- If router uses channel 11 → set ESP-NOW to 1 or 6

On controller: `CHANNEL 6` (persisted)
On robot: change `#define ESPNOW_CHANNEL` in `espnow-protocol.h` and reflash.

Use the `WiFi_Channel_Scanner` sketch to find clear channels.

### Protocol Overview

Messages are binary structs over ESP-NOW. Controller ↔ Computer uses newline-terminated text. See `software/esp-now/espnow-protocol.h` for all struct definitions.

```
Computer           Controller (ESP32-C3)           Robot (ESP32-S3)
────────           ────────────────────           ─────────────────
"CMD wave\n"  ──→  parse  ──→  sesame_motion_cmd_t  ──→  onEspNowRecv()
                            {msg_type=0x01,           ↓
                             command="wave"}      ──→  currentCommand="wave"
                                                      runWavePose()
                                              ──→  send ACK
                                                        ↓
"OK\n"         ◄──  (ACK received)  ◄────────────────
```

### Serial Command Reference

Connect to the controller's USB serial port at **115200 baud**:

#### Motions
```
CMD forward   CMD backward   CMD left   CMD right
CMD rest      CMD stand      CMD wave   CMD dance
CMD swim      CMD point      CMD pushup CMD bow
CMD cute      CMD freaky     CMD worm   CMD shake
CMD shrug     CMD dead       CMD crab
STOP
```

#### Faces
```
FACE happy      FACE sad        FACE angry     FACE surprised
FACE sleepy     FACE love       FACE excited   FACE confused
FACE thinking   FACE idle       FACE default   FACE talk_happy
FACE talk_sad   ... (all talk_* variants)
```

#### Servos
```
SERVO 0 135           → Set motor R1 to 135°
SERVO_ALL 90          → All motors to 90°
```
Channels: 0=R1 1=R2 2=L1 3=L2 4=R4 5=R3 6=L3 7=L4

#### Trims
```
TRIM_SET 0 5          → +5° offset on motor R1
TRIM_GET              → Print all 8 trims
TRIM_RESET            → Zero all trims and save
```

#### Configuration
```
CONFIG_SET frameDelay 120
CONFIG_SET walkCycles 15
CONFIG_SET motorCurrentDelay 60
CONFIG_SET faceFps 12
CONFIG_GET
```

#### System
```
STATUS       → cmd=<current> face=<current>
PING         → PONG rtt=<ms>
MAC          → Show controller's MAC
CHANNEL      → Show current channel
CHANNEL 6    → Change channel (restart required)
SET_ROBOT_MAC DC:54:75:C8:43:00 → Persist robot MAC
HELP         → Show full help
```

### Python Control Example

```python
import serial, time

ser = serial.Serial('/dev/ttyUSB0', 115200, timeout=1)
time.sleep(2)

def cmd(c):
    ser.write(f"{c}\n".encode())
    time.sleep(0.1)
    print(ser.read_all().decode())

cmd("PING")
cmd("CMD wave")
cmd("FACE happy")
cmd("TRIM_GET")
ser.close()
```

### Serial Debug on the Robot

The robot's serial port has a full CLI that works alongside ESP-NOW:

```
help                → Show all debug commands
mac                 → Print robot MAC + channel
rn wf               → Walk forward
rn st               → Stand pose
0 90                → Set motor 0 to 90°
all 90              → Set all motors to 90°
subtrim             → List trim values
st 3 10             → Set motor 3 trim +10°
settings reset      → Reset to defaults
```

See `software/esp-now/DEBUG_CHECKS.md` for the full troubleshooting guide.

### Files

| File | Description |
|---|---|
| `firmware/sesame-firmware-espnow.ino` | Robot firmware, ESP-NOW receiver (ESP32-S3) |
| `software/esp-now/ESP32_C3_Sesame/ESP32_C3_Sesame.ino` | Controller firmware (ESP32-C3) |
| `software/esp-now/espnow-protocol.h` | Shared binary protocol header |
| `software/esp-now/DEBUG_CHECKS.md` | Quick debug reference |

### Troubleshooting Quick Table

| Symptom | Likely Cause | Fix |
|---|---|-----|
| `PING` times out | Robot MAC unknown to controller | `SET_ROBOT_MAC <robot_mac>` |
| No command response | Channel mismatch | Ensure both use `ESPNOW_CHANNEL` = same value |
| Latency >20 ms | Far apart / interference | Move closer; use channel 6/11; scan with WiFi scanner |
| Controller says "peer not registered" | Robot never received first packet | Send `PING`; check robot log for auto-registration |
| Servo jitter | `motorCurrentDelay` too low | `CONFIG_SET motorCurrentDelay 80` |

Full debug reference: `software/esp-now/DEBUG_CHECKS.md`

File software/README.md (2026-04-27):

# Software

Software applications for making the most of your Sesame Robot.

## Tools

### [Sesame Studio](sesame-studio/)
A visual Python-based tool for creating animations.

- **Graphical Interface**: layout joints on screen with guides.
- **Code Generator**: outputs C++ code ready for firmware.

[Go to Sesame Studio Documentation ->](sesame-studio/README.md)

### ESP-NOW Controller (`esp-now/`)
Lightweight wireless control using ESP-NOW (no WiFi router needed). An ESP32-C3 Mini connects via USB to your computer and bridges serial commands to the robot over ESP-NOW radio.

- **Low latency**: 1-5 ms round-trip vs 20-100ms over HTTP
- **No network setup**: Peer-to-peer, no access point required
- **Simple protocol**: Text commands over serial (easy from Python, shell, Node.js)
- **Full feature parity**: motions, faces, servo trim, configuration

**Components:**
- `espnow-protocol.h` — shared binary protocol header
- `ESP32_C3_Sesame/` — controller firmware (ESP32-C3)
- `sesame-firmware-espnow.ino` — robot firmware (ESP32-S3)

[Go to ESP-NOW Documentation ->](esp-now/ESP32_C3_Sesame/README.md)

[ESP-NOW Quick Debug Checks ->](esp-now/DEBUG_CHECKS.md)

### Sesame Companion App
A Python application for advanced robot control and interaction over your local network.

- **Voice Control**: Integrate with speech recognition for voice commands.
- **Emotion Mapping**: Automatically set robot expressions based on sentiment analysis.
- **Remote API Control**: Send commands and face changes via the JSON API.
- **Network Mode**: Requires robot firmware with network mode enabled.
- **Home Automation**: Example integrations with Home Assistant and other platforms.

**Note:** The Companion App is a separate repository and requires the latest firmware with network mode enabled.

[Go to Sesame Companion App Repository ->](https://github.com/dorianborian/sesame-companion-app)

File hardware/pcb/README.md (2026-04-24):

# PCB Schematics

Electronic schematics and PCB designs for the Sesame Robot Project. There are two versions of the Sesame Distro Board available: V2 (current) and V1 (legacy).

> [!NOTE]
> **For Sesame Build Kits:** All Sesame Build Kits include a pre-flashed Sesame Distro Board V2, so you don't need to order or assemble a board separately.

> [!TIP]
> **Building from Scratch?** If you're building a Sesame Robot from scratch, we recommend using the **S2 Mini with hand wiring approach** for the easiest assembly experience. The V2 distro board uses advanced SMD components that require specialized soldering skills or PCB assembly services.

---

## Sesame Distro Board V2 (Current)

The **Sesame Distro Board V2** is the latest version and features:
- **Power Delivery (PD) support** - Works with USB-C PD power supplies
- **Battery power support** - Also works with battery power
- **Compact SMD design** - All surface-mount components for a professional finish
- **Included in all Sesame Build Kits** - Pre-flashed and ready to use

### Assembly Options for V2

The V2 board consists entirely of SMD (surface-mount) components, which are **advanced to hand solder**. We recommend:

1. **PCB Assembly Service (Recommended):** Use [PCBway's PCB assembly service](https://www.pcbway.com/pcb-assembly.html) to have the board professionally assembled. Upload the Gerber, BOM, and Pick-and-Place files to their assembly service.
2. **Hand Soldering (Advanced Only):** Only attempt hand soldering if you're experienced with SMD components and have the proper tools (hot air station, fine-tip soldering iron, flux, etc.).

### V2 Files Available

All files are located in the [`distro-v2/`](distro-v2/) directory:
- **Schematic source:** `SCH_Sesame-Distro-Board-V2_2026-03-06.json` - EasyEDA source design file for the V2 schematic
- **Gerber file:** `Gerber_Sesame-Distro-V2_PCB.zip` - For PCB fabrication
- **BOM file:** `BOM_Sesame-Distro-V2.csv` - Bill of materials for SMD components
- **Pick-and-Place file:** `PickAndPlace_PCB_Sesame-Distro-V2.csv` - Component placement data for assembly

### PCBway / JLCPCB Sourcing Notes

When uploading the BOM to PCBway or JLCPCB for assembly, note the following three components that require special handling:

| Designator | Issue | Corrected Part | LCSC # |
|---|---|---|---|
| `U5`, `U7` | **Solder Pads** — these are copper pads only, no physical component is needed. Remove these lines from the BOM when ordering assembly. | N/A | N/A |
| `5-12V` | 2-pin 3.5 mm screw terminal. Original part `1984617` (Phoenix Contact) cannot be sourced. | `XY302V-3.5-2P` | [C784940](https://www.lcsc.com/product-detail/C784940.html) |
| `JST-XH` | 4-pin JST XH connector. Original `JST-XH-4-PIN` cannot be sourced. | `B4B-XH-A(LF)(SN)` | [C144395](https://www.lcsc.com/product-detail/C144395.html) |

The BOM CSV has already been updated with the corrected parts. The solder-pad rows are marked **"No Part Required"** in the Name field so they are easy to identify and exclude.

---

## Sesame Distro Board V1 (Legacy)

> [!CAUTION]  
> The Sesame Distro Board V1 is now **phased out** but still supported. V1 has some limitations: it won't run on tethered power (e.g., USB-C) and is harder to assemble than other options. V1 is still supported with wiring guides and firmware and works on battery power. If you have a V1 board, you can still use it successfully.

The Distro Board V1 pairs with the ESP32-DevKitC-32E.

> [!IMPORTANT]
> **ESP32 Pin Header Requirement:** The distro board V1 stacks on top of the ESP32-DevKitC-32E, so you need an ESP32 board **without pre-soldered pin headers**. If your board came with headers already soldered on the top, you will need to desolder all of the headers and flip them to the bottom side of the ESP32 board so the distro board can mount on top.

### V1 Board Schematic:

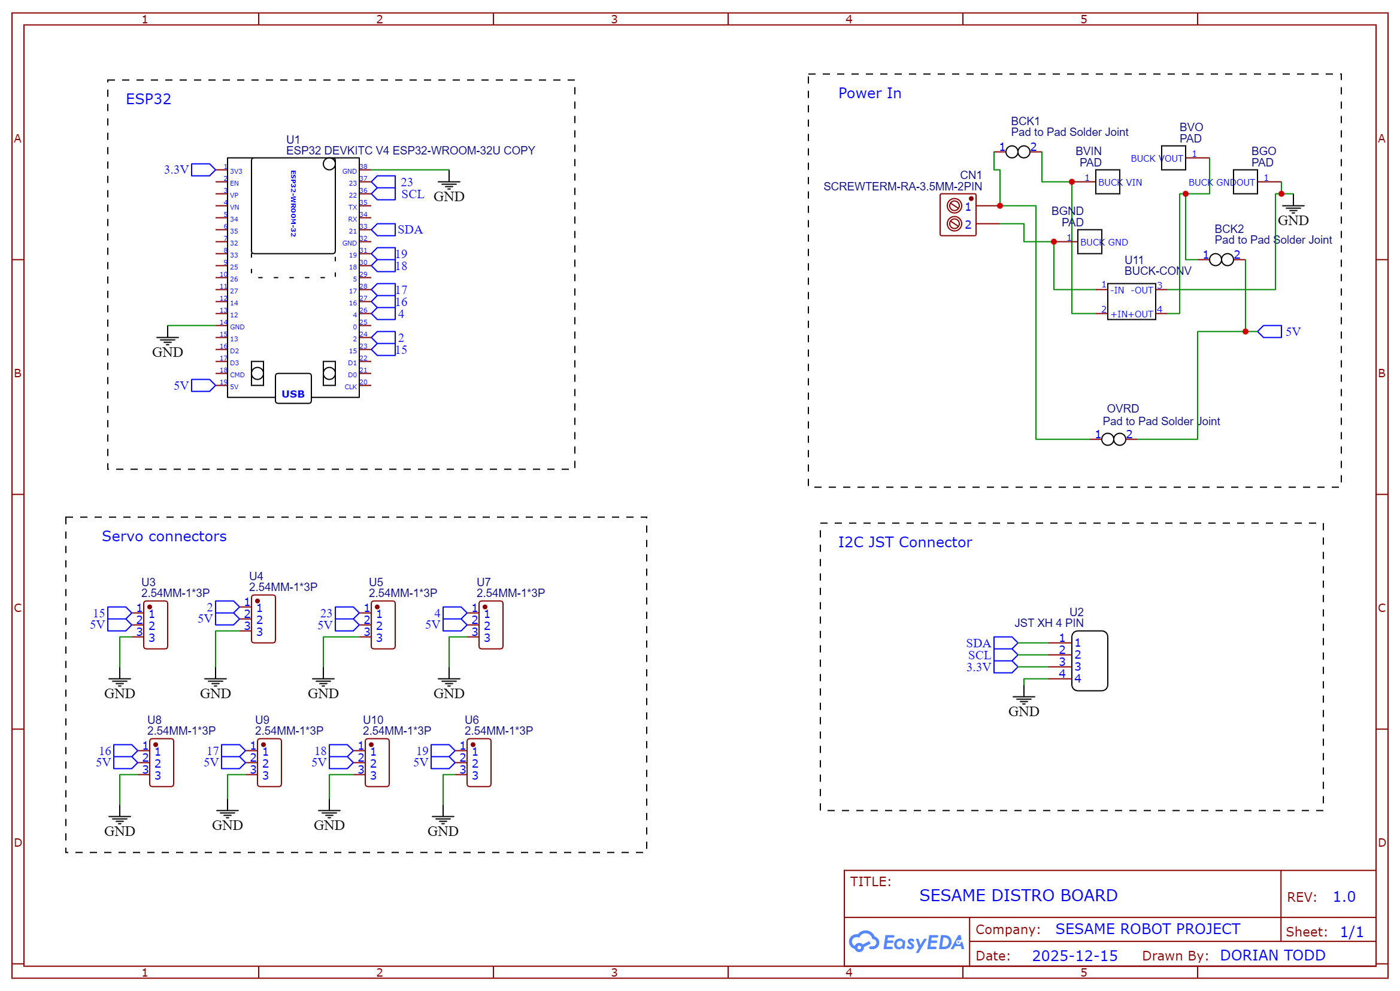
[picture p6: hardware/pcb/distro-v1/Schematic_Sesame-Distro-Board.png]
Schematic_Sesame-Distro-Board


### V1 Files Available

All files are located in the [`distro-v1/`](distro-v1/) directory.

---

## PCBway Sponsorship

**PCBway Sponsorship**

This project was sponsored by [PCBway](https://www.pcbway.com/), who manufactured the custom distro boards. PCBway offers high-quality PCB fabrication services with fast turnaround times and excellent customer support. 

If you're building your own Sesame Robot, PCBway is a great option for getting professional-quality PCB fabrication and assembly services at reasonable prices:
- **PCB Fabrication:** Upload Gerber files to get boards manufactured
- **PCB Assembly:** Upload Gerber, BOM, and Pick-and-Place files for fully assembled boards (recommended for V2)

pcbs-from-pcbway

---

## How to Order

### Ordering V2 Boards (Recommended)

**Option 1: PCB Assembly Service (Recommended)**

1. Go to [PCBway's PCB Assembly service](https://www.pcbway.com/pcb-assembly.html)
2. Upload the Gerber file: `distro-v2/Gerber_Sesame-Distro-V2_PCB.zip`
3. Upload the BOM file: `distro-v2/BOM_Sesame-Distro-V2.csv`
4. Upload the Pick-and-Place file: `distro-v2/PickAndPlace_PCB_Sesame-Distro-V2.csv`
5. Confirm board specifications and component availability
6. Place your order to receive fully assembled boards

**Option 2: Fabrication Only (For Advanced Users)**

1. Download the Gerber file from [`distro-v2/Gerber_Sesame-Distro-V2_PCB.zip`](distro-v2/Gerber_Sesame-Distro-V2_PCB.zip)
2. Upload to [PCBway](https://www.pcbway.com/) or another PCB manufacturer
3. Confirm board specifications in the preview
4. Order the bare PCBs and hand-solder SMD components yourself (advanced)

### Ordering V1 Boards (Legacy)

1. Download the Gerber file from [`distro-v1/Gerber_Sesame-Distro-Board_PCB_Sesame-Distro-Board_V1.zip`](distro-v1/Gerber_Sesame-Distro-Board_PCB_Sesame-Distro-Board_V1.zip)
2. Upload to [PCBway](https://www.pcbway.com/) or another PCB manufacturer
3. Confirm board specifications in the preview
4. Place your order to receive bare V1 boards

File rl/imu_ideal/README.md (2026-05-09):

# sesameRL

RL training environment for the 4-legged, 8-DOF [Sesame quadruped,](https://github.com/dorianborian/sesame-robot/) built on [mjlab](https://mujocolab.github.io/mjlab/). PPO via `rsl_rl`, TensorBoard logging, and the [Sesame URDF](urdf_model/Sesame.urdf) loaded directly into a MuJoCo `MjSpec`.

Every observation, reward, event, curriculum stage, and PPO hyperparameter lives in the [config.py](config.py).

---

## Quick start

- Download the repository
- Create and activate a UV virtual environment:
  ```bash
  uv venv          # creates .venv directory
  source .venv/bin/activate  # on Windows: .venv\Scripts\activate
  ```
- Install mjlab (includes PyTorch and other dependencies):
  ```bash
  uv pip install git+https://github.com/mujocolab/mjlab.git
  ```
- From the base folder, with the virtual environment active:

```bash
python validate.py                                          # sinusoidal joint drive, no policy
python sequences.py --list                                  # list firmware gait sequences
python sequences.py --sequence walk                         # replay a firmware sequence
python train.py                                             # full PPO run
python play.py                                              # auto-loads latest checkpoint
python play.py --checkpoint-file logs/<run>/model_<n>.pt    # play a specific checkpoint
tensorboard --logdir logs                                   # monitor training
```

## Configuration

All experiment configurations are in [`config.py`](config.py). The file is organized into sections:

- **Robot**: URDF paths, joint mappings, default poses, actuator gains
- **Sim-to-real fidelity**: Hardware-realistic defaults (actuator delay, motor model, sensor noise)
- **Scene / simulation**: Number of parallel environments, episode length, termination conditions
- **Observations**: Which sensor readings are fed to the policy (can enable/disable for sim-to-real transfer)
- **Rewards**: Reward functions and weights for the velocity-tracking task
- **Events**: Domain randomization and perturbations (push robot, encoder bias, etc.)
- **Commands**: Velocity command curriculum for progressive learning
- **Training (PPO)**: Hyperparameters for the rsl_rl PPO trainer
- **Helpers**: Functions to get enabled configs

Key configuration flags for sim-to-real transfer:
- `OBS_JOINT_VEL_ENABLED`: `False` — no velocity sensor on hardware; policy infers joint state from commanded position history
- `OBS_BASE_LIN_VEL_ENABLED`: `True` — velocity estimated on hardware by integrating MPU6050 accelerometer (after gravity removal via DMP orientation); sim models this with 0.2 m/s RMS Gaussian noise
- `ACTUATOR_DC_MOTOR_ENABLED`: Set to `True` to use realistic DC motor model (requires retraining)
- `OBS_JOINT_POS_DELAY_ENABLED`: `True` — simulates 40–80 ms open-loop servo command latency with 3° noise
- `IMU_NOISE_ENABLED`: `True` — adds MPU6050-calibrated Gaussian noise to gyro, accelerometer, and lin vel estimate

### Observation space

| Observation | Dim | Source on hardware | Noise modelled |
|---|---|---|---|
| `base_lin_vel` | 3 | Accelerometer integration via DMP | 0.2 m/s RMS drift |
| `base_ang_vel` | 3 | MPU6050 gyroscope | 0.005 rad/s |
| `projected_gravity` | 3 | MPU6050 accelerometer (DMP) | 0.004 (dimensionless) |
| `joint_pos` | 8 | Last *commanded* angle (open-loop) | 0.05 rad + 40–80 ms delay |
| `actions` | 8 | Previous policy output | — |
| `command` | 3 | Target (vx, vy, wz) from joystick | — |
| **Total** | **28** | | |

`joint_vel` is excluded — no velocity sensor exists. The policy has an implicit proxy via `joint_pos − actions` (commanded rate).

### Actor vs critic network

The actor runs on the ESP32 at deployment; the critic is training-only.

| | Hidden dims | ~Params | ~Size |
|---|---|---|---|
| Actor | (64, 128, 64) | 19 k | 75 KB |
| Critic | (256, 512, 256, 128) | 303 k | 1.2 MB |

The actor fits in ESP32 internal SRAM (~75 KB vs ~200 KB available). Observation normalization is left off; the 28-element input is already bounded by sensor ranges and the drift noise models.

### Simulation Timesteps & Control Frequency

The simulation uses a two-level timing approach based on the comments in config.py:

1. **Physics Timestep (`dt`)**: 5ms (0.005s) - defined in the base mjlab velocity config as `mujoco.timestep = 0.005`
2. **Decimation**: 4 - meaning the simulation advances 4 physics steps per control step
3. **Control Frequency**: 50Hz - calculated as `1 / (dt * decimation) = 1 / (0.005 * 4) = 50Hz`

This means:
- Each control step (policy inference) corresponds to 20ms of simulated time
- The policy runs at 50Hz (every 20ms)
- Within each control step, the physics simulator runs 4 sub-steps of 5ms each
- Actuator delays are specified in physics steps: 40ms hardware delay = 8 physics steps at 5ms/dt

These values can be verified in:
- `env_cfg.py`: Uses `sesame_flat_env_cfg()` which builds on the base velocity config
- `config.py`: Lines 63-75 document the timing relationships
- `validate.py`: Line 79 shows `dt = env_cfg.decimation * env_cfg.sim.mujoco.timestep` calculation

## Firmware Sequence Replay (`sequences.py`)

`sequences.py` translates the 19 pre-programmed motion sequences from
[`firmware/movement-sequences.h`](../../firmware/movement-sequences.h) into
MuJoCo simulation actions and replays them using the same environment and
viewer stack as `validate.py`. Use it to verify gait geometry in simulation
before deploying to hardware.

### Motor ID → URDF Joint Mapping

The firmware addresses servos by index (0–7). The mapping comes from the
firmware `ServoName` enum and the robot's web UI slider labels:

| Servo index | Web UI label | URDF joint | Role |
|:---:|:---:|:---:|---|
| 0 | S0 / R1 | Joint_R1 | Front-right hip |
| 1 | S1 / R2 | Joint_R2 | Rear-right hip |
| 2 | S2 / L1 | Joint_L1 | Front-left hip |
| 3 | S3 / L2 | Joint_L2 | Rear-left hip |
| 4 | S4 / R4 | Joint_R4 | Rear-right knee |
| 5 | S5 / R3 | Joint_R3 | Front-right knee |
| 6 | S6 / L3 | Joint_L3 | Front-left knee |
| 7 | S7 / L4 | Joint_L4 | Rear-left knee |

### Angle Conversion

Firmware angles are degrees [0, 180]. They are converted to MuJoCo actions via:

```
target_rad = servo_degrees × π / 180
action[i]  = (target_rad − default_angle[joint]) / ACTION_SCALE
```

where `default_angle` comes from `config.DEFAULT_JOINT_ANGLES` and
`ACTION_SCALE` is `config.ACTION_SCALE`.

### Available Sequences

All 19 sequences are translated 1-to-1 from the firmware:

| Name | Description | Notes |
|---|---|---|
| `rest` | All servos to 90° | Flat rest pose |
| `stand` | Hip/knee to standing pose | Baseline upright stance |
| `wave` | Left arm wave | 4 cycles |
| `dance` | Hip sway with knee bounce | 5 cycles |
| `swim` | Hip alternation | 4 cycles |
| `point` | Extended pointing pose | 2 s hold |
| `pushup` | Front knee push-up | 4 reps |
| `bow` | Full forward bow | 3 s hold |
| `cute` | Rear leg wiggle | 5 cycles |
| `freaky` | Front arm flail | 3 cycles |
| `worm` | Knee crawl alternation | 5 cycles |
| `shake` | Rear leg shake | 5 cycles |
| `shrug` | Knee-up shrug pose | 1.5 s hold |
| `dead` | Collapse to flat | — |
| `crab` | Crab walk side-step | 5 cycles |
| `walk` | Forward trot gait | `--cycles` repeats |
| `backward` | Backward trot gait | `--cycles` repeats |
| `turn_left` | Left pivot | `--cycles` repeats |
| `turn_right` | Right pivot | `--cycles` repeats |

### Usage

```bash
# List available sequence names
python sequences.py --list

# Play a single named sequence
python sequences.py --sequence stand
python sequences.py --sequence walk
python sequences.py --sequence dance --viewer native

# Control walk/turn loop count (default 3)
python sequences.py --sequence walk --cycles 5

# Cycle through all 19 sequences in order
python sequences.py
```

### Web UI — switching sequences at runtime

When using the default Viser viewer a **Sequence** dropdown appears at the
top of the control panel (above the built-in Controls / Visualization /
Groups tabs).

**Switching behaviour:**
1. The environment is reset — any accumulated velocity or tilt is cleared and
   the robot is placed back at its safe starting pose.
2. The player automatically prepends a `rest` keyframe before the new
   sequence so the robot always returns to a neutral, grounded pose before
   executing the next motion.

The default selection is `rest` (or whatever `--sequence` was passed on the
command line).  The `(all)` option cycles through every sequence in order,
also starting from rest.

The native MuJoCo viewer (`--viewer native`) does not have a GUI API and
falls back to command-line selection only.

### Architecture

`SequencePlayer` is a policy-compatible callable that steps through a list
of `Keyframe` objects (each a complete 8-servo angle snapshot + duration in
ms). It advances to the next keyframe when the current one expires and
cycles indefinitely. A `threading.Lock` guards all state so the Viser
callback thread (dropdown changes) and the sim-loop thread (policy calls)
never race.

`sequences.py` creates its own `viser.ViserServer` and adds the Sequence
dropdown before handing the server to `ViserPlayViewer`. The viewer appends
its own tabs to the same server, so everything appears in one panel.

The `_Builder` helper mirrors the firmware's stateful `setServoAngle` +
`delayWithFace` pattern: servo state is cumulative across calls, and each
`delay(ms)` snapshots the full 8-servo state into a `Keyframe`. Loop bodies
are expanded inline to their firmware-specified repeat counts.

---

## Running Experiments

### Training

Run a standard PPO training experiment:

```bash
python train.py
```

This will:
- Use the experiment name from `config.EXPERIMENT_NAME` ("sesame_velocity")
- Run for `config.MAX_ITERATIONS` (10,000) PPO iterations
- Use `config.NUM_ENVS` (4096) parallel environments
- Save logs to `logs/<timestamp>/` and checkpoints every 100 iterations
- Use seed `config.SEED` (1) for reproducibility

### Customizing Training

Override any config parameter via command line:

```bash
# Smoke test with fewer iterations
python train.py --max-iterations 20

# Custom experiment name
python train.py --run-name my_first_run

# Reduce parallel environments (for limited VRAM)
python train.py --num-envs 1024

# Change random seed
python train.py --seed 42

# Combine multiple overrides
python train.py --max-iterations 500 --run-name test --num-envs 2048
```

### Evaluation / Visualization

View the latest trained policy:

```bash
python play.py
```

This auto-loads the newest checkpoint from `logs/<timestamp>/` and runs it with the Viser web viewer.

To load a specific checkpoint:

```bash
python play.py --checkpoint-file logs/2026-05-03_10-30-00/model_500.pt
```

Use the native MuJoCo viewer instead of Viser:

```bash
python play.py --viewer native
```

### Monitoring Training

Launch TensorBoard to view training metrics:

```bash
tensorboard --logdir logs
```

This will show:
- Reward curves (episode reward, individual reward components)
- Policy losses (actor/critic loss, entropy, KL divergence)
- Command tracking performance
- Episode length and success statistics

## Experiment Workflow

1. **Modify config.py** to adjust robot/sim settings, rewards, or curriculum
2. **Run training**: `python train.py [--max-iterations N] [--run-name NAME]`
3. **Monitor progress**: `tensorboard --logdir logs`
4. **Evaluate**: `python play.py` or `python play.py --checkpoint-file PATH/TO/MODEL.PT`
5. **Iterate**: Adjust config based on results and repeat

---

## Layout

```
sesameRL/
├── validate.py        sinusoidal joint drive — sanity check before training
├── sequences.py       replay firmware gait sequences in simulation
├── config.py          all the configs, main place to edit
├── train.py           run for training
├── play.py            run for sandbox play
├── sesame_robot.py    imports robot from URDF file
├── env_cfg.py         composes mjlab environment from config.py
├── urdf_model/        Sesame.urdf + STL meshes
├── images/            visualization assets
└── logs/              rsl_rl run dirs (TensorBoard + checkpoints + params snapshots)
```

## Visualization

The `images/` directory contains visualizations of the robot and training results.

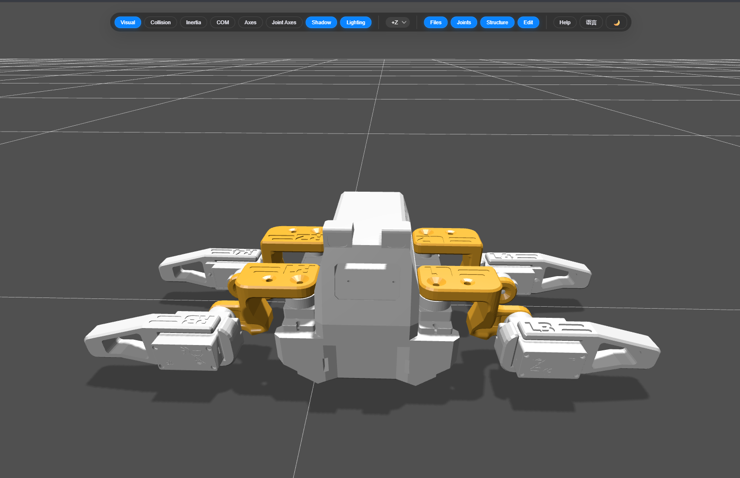
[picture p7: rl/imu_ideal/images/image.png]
Sesame Quadruped


---

## Robot notes

Link / joint naming inherited from the Sesame project:

| Link | Role | Hip joint | Knee joint |
|---|---|---|---|
| Link_L3 | Front-left | Joint_L1  | Joint_L3 |
| Link_L4 | Rear-left | Joint_L2  | Joint_L4 |
| Link_R3 | Front-right  | Joint_R1  | Joint_R3 |
| Link_R4 | Rear-right | Joint_R2  | Joint_R4 |

---

## Roadmap

- [ ] URDF checks
	- [ ] Solidworks->URDF is not very mature, so some positions/axes might be off
	- [X] Starting orientation is garbage visually. Has no adverse effect, but would be nice if it was standing straight.
- [ ] Check the [TODO] and [OPT] tags in [config.py](config.py)
    - [ ] Tune kp-kd values
    - [X] Make the NN small enough to fit ESP32 — actor (64,128,64) ≈ 75 KB
    - [X] Current observations are not realizable with existing hardware — lin vel now uses accelerometer-integration model; joint vel excluded; joint pos uses commanded angle + delay
    - [ ] Currently uses curriculum, can upgrade to hierarchical learning
    - [ ] Play with rewards for better locomotion
- [ ] Terrain is flat, can upgrade to a rough terrain
- [ ] Sim-to-real preparation (needs extended hardware)

## Credits
Original concept and skeleton code from @karabibik

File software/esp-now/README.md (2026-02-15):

# ESP-NOW Speed Test - Setup Instructions

## Overview
This test measures ESP-NOW communication performance between two ESP32 boards:
- **ESP32-C3 Mini**: Controller/Receiver (connected to computer)
- **AtomS3 Lite ESP32-S3**: Sensor/Transmitter (simulating robot sensor)

## Setup Steps

### 1. Install Required Library
The AtomS3 sketch requires the FastLED library for RGB LED control:
1. Open Arduino IDE
2. Go to Tools → Manage Libraries
3. Search for "FastLED"
4. Install "FastLED by Daniel Garcia"

### 2. Program ESP32-C3 Mini First
### 2. Program ESP32-C3 Mini First
1. Open `ESP32_C3_Controller.ino` in Arduino IDE
2. Select board: "ESP32C3 Dev Module" (or appropriate C3 board)
3. Upload the sketch
4. Open Serial Monitor (115200 baud)
5. **COPY THE MAC ADDRESS** displayed on startup (format: XX:XX:XX:XX:XX:XX)

### 3. Program AtomS3 Lite Second
1. Open `AtomS3_Sensor.ino` in Arduino IDE
2. **IMPORTANT**: Replace the MAC address on line 11 with the C3 Mini's MAC address:
   ```cpp
   uint8_t c3MiniAddress[] = {0xXX, 0xXX, 0xXX, 0xXX, 0xXX, 0xXX};
   ```
3. Select board: "ESP32S3 Dev Module" (or M5Stack AtomS3)
4. Upload the sketch
5. Open Serial Monitor (115200 baud)
6. **COPY THE MAC ADDRESS** displayed

### 4. Update C3 Mini with AtomS3 MAC
1. Go back to `ESP32_C3_Controller.ino`
2. Replace the MAC address on line 11 with the AtomS3's MAC address
3. Re-upload to the C3 Mini

### 5. Run the Test
1. Both boards should now communicate
2. **Press the button on the AtomS3** to start/stop transmission
3. Watch the RGB LED for status (see LED Status Guide below)
4. Statistics appear every 2 seconds on both serial monitors when transmitting

## AtomS3 Controls

### Button Control
- **Press once**: Start transmission (LED turns green)
- **Press again**: Stop transmission (LED returns to breathing blue)
- Transmission only happens when active - saves power and lets you control when to test

### LED Status Guide
- **Cyan**: Initializing ESP-NOW
- **Blue (breathing)**: Ready, waiting for button press
- **Green (solid)**: Actively transmitting sensor data
- **Yellow (pulse)**: Receiving servo commands from C3 (overlays on green)
- **Red (blinking)**: Connection error or repeated send failures

## Test Configuration

### WiFi Channel Selection (Important!)
To avoid interference with your local WiFi network, you should configure ESP-NOW to use a different channel:

1. **Find your router's WiFi channel:**
   - Check your router's admin page (usually 192.168.1.1 or 192.168.0.1)
   - Look for "Wireless Settings" or "WiFi Channel"
   - Note which channel your 2.4GHz network uses (typically 1, 6, or 11)

2. **Choose an ESP-NOW channel:**
   - Pick a non-overlapping channel different from your WiFi
   - Best options: 1, 6, or 11 (these don't overlap with each other)
   - Example: If your WiFi is on channel 6, use channel 1 or 11 for ESP-NOW

3. **Set the channel in BOTH sketches:**
   - In `ESP32_C3_Controller.ino` line 14: `#define ESPNOW_CHANNEL 1`
   - In `AtomS3_Sensor.ino` line 19: `#define ESPNOW_CHANNEL 1`
   - **Both must use the SAME channel!**

**Channel Reference:**
- Channels 1, 6, 11 don't overlap - best for avoiding interference
- If your WiFi is on channel 1, use 6 or 11
- If your WiFi is on channel 6, use 1 or 11
- If your WiFi is on channel 11, use 1 or 6

### Default Settings
- **Send Rate**: AtomS3 sends sensor data every 5ms (200 Hz)
- **Processing Loop**: C3 Mini processes every 10ms (100 Hz)
- **Data Sizes**: 
  - Sensor data: 16 bytes (3 floats + timestamp)
  - Servo data: 20 bytes (8 uint16_t + timestamp)

### Adjusting Test Parameters

**Change Send Rate** (in AtomS3_Sensor.ino, line 44):
```cpp
const int SEND_INTERVAL_MS = 5;  // Try 1, 5, 10, 20, 50
```

**Change Processing Rate** (in ESP32_C3_Controller.ino, line 70):
```cpp
if (processStart - lastProcessTime >= 10) {  // Try 5, 10, 20, 50
```

## Metrics Explained

### On C3 Mini (Controller)
- **Receive Rate**: Packets/sec from AtomS3
- **Send Rate**: Servo commands/sec sent back
- **Avg Latency**: Time from when AtomS3 sent data until C3 received it
- **Min/Max Latency**: Best and worst one-way latency

### On AtomS3 (Sensor)
- **Send Rate**: Sensor packets/sec transmitted
- **Success Rate**: % of packets sent successfully
- **Receive Rate**: Servo commands/sec received from C3
- **Round-Trip Time**: Time from sending sensor data to receiving servo commands back

## Performance Expectations

Typical ESP-NOW performance:
- **Latency**: 1-5 ms (one-way)
- **Round-Trip**: 5-20 ms
- **Max Throughput**: 200-500 packets/sec (depends on packet size and distance)
- **Range**: 100-200m line of sight, 10-50m with obstacles

### Observed Test Results

#### Standard Mode (5ms Interval)
During a standard test run with default settings:
- **Send Rate**: ~185 packets/sec
- **Receive Rate**: ~91 packets/sec (at 10ms processing loop)
- **Success Rate**: 100.0%
- **Latencies**:
  - **Average Round-Trip**: 2.85 - 2.92 ms
  - **Minimum Round-Trip**: 0.81 - 2.77 ms
  - **Maximum Round-Trip**: 3.99 - 5.09 ms

#### High-Performance Mode (1ms Interval)
Pushing the limits with `SEND_INTERVAL_MS = 1`:
- **Send Rate**: ~478 packets/sec
- **Receive Rate**: ~94 packets/sec
- **Success Rate**: 100.0%
- **Latencies**:
  - **Average Round-Trip**: **0.80 - 1.10 ms**
  - **Minimum Round-Trip**: 0.03 - 0.59 ms
  - **Maximum Round-Trip**: 2.08 - 3.13 ms

These results confirm that the link is highly stable and capable of supporting extremely high-frequency control loops with sub-1ms round-trip latency when optimized.

## Troubleshooting

**LED not working:**
1. Verify FastLED library is installed
2. Check correct board selection (ESP32S3 Dev Module)
3. Some AtomS3 clones use different LED pins - try pin 2 if pin 35 doesn't work

**Button not responding:**
1. Wait for initialization (cyan LED) to complete
2. LED should turn blue when ready
3. Press firmly - there should be a tactile click
4. Check serial monitor for "TRANSMISSION STARTED/STOPPED" messages

**No communication:**
1. Verify MAC addresses are correctly copied (include 0x prefix)
2. Check both boards are on same WiFi channel (auto-negotiated)
3. Ensure boards are within range (start close, ~1m apart)

**High packet loss:**
- Check WiFi channel configuration - make sure both boards use the same channel
- If using the same channel as your WiFi, change to a non-overlapping channel
- Increase SEND_INTERVAL_MS on AtomS3
- Check for WiFi interference (microwaves, other 2.4GHz devices)
- Reduce distance between boards

**Inconsistent latency:**
- Normal with WiFi congestion
- Try changing WiFi channel if possible
- Reduce other 2.4GHz devices nearby

## Testing Different Scenarios

### Maximum Throughput Test
Set `SEND_INTERVAL_MS = 1` on AtomS3 to send at ~1000 Hz and observe packet loss.

### Latency Test
Set `SEND_INTERVAL_MS = 50` for slower rate, measure minimum achievable latency.

### Real-World Robot Simulation
- Keep default 5ms send rate (200 Hz - typical IMU rate)
- Monitor if C3 can keep up with 10ms processing loop
- Check round-trip times stay under 20-30ms for responsive control

## Next Steps

After testing, you can:
1. Replace simulated sensor data with real MPU6050 readings
2. Add actual servo control code on AtomS3
3. Implement error handling and retry logic
4. Add acknowledgment system for critical commands
5. Optimize packet structures for your specific needs

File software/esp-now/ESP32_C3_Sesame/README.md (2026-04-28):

# ESP-NOW Sesame Controller

Control the Sesame Robot wirelessly using ESP-NOW instead of WiFi. An ESP32-C3 Mini connects to your computer or Raspberry Pi via USB and bridges text serial commands to the robot over ESP-NOW.

## Architecture

```
┌─────────────┐    USB Serial     ┌─────────────────┐    ESP-NOW     ┌──────────────┐
│  Computer / │ ←──(text cmds)──→ │  ESP32-C3 Mini  │ ←──(binary)──→ │  ESP32-S3    │
│  Raspberry  │   115200 baud     │  (Controller)   │   ~1-5ms RTT  │  (Robot)     │
│  Pi         │                   │                 │               │  8 Servos    │
└─────────────┘                   └─────────────────┘               │  OLED Face   │
                                                                    └──────────────┘
```

**Why ESP-NOW instead of WiFi?**
- Sub-5ms latency (vs 20-100ms for HTTP over WiFi)
- No access point or router needed
- Lower power consumption
- More reliable — no TCP overhead, reconnection delays, or DNS issues
- Direct peer-to-peer at the radio level

## Hardware Required

| Component | Role | Notes |
|---|---|---|
| **ESP32-C3 Mini** | Controller (USB bridge) | Any ESP32-C3 board works |
| **ESP32-S3 board** | Robot (runs servos + display) | With Sesame Distro Board |
| **USB cable** | Computer ↔ Controller | USB-C or Micro-USB depending on board |

No wiring between the two boards — they communicate wirelessly.

## Quick Start

### 1. Flash the Robot Firmware

1. Open `firmware/sesame-firmware-espnow.ino` in Arduino IDE
2. Select board: **ESP32S3 Dev Module** (or your specific S3 board)
3. Install required libraries (same as original firmware):
   - `ESP32Servo` v3.0.9
   - `Adafruit SSD1306`
   - `Adafruit GFX Library`
4. Upload the sketch
5. Open Serial Monitor (115200 baud)
6. **Copy the MAC address** printed at startup:
   ```
   === Sesame Robot (ESP-NOW) ===
   MAC Address: DC:54:75:C8:43:00
   ESP-NOW Channel: 1
   ```

### 2. Flash the Controller Firmware

1. Open `software/esp-now/ESP32_C3_Sesame/ESP32_C3_Sesame.ino` in Arduino IDE
2. Select board: **ESP32C3 Dev Module**
3. Upload the sketch
4. Open Serial Monitor (115200 baud)
5. Set the robot's MAC address (from step 1):
   ```
   SET_ROBOT_MAC DC:54:75:C8:43:00
   ```
   This is saved to flash — you only need to do it once.

### 3. Test the Connection

```
PING
```
Expected response:
```
PONG rtt=2.35ms
```

Try a motion:
```
CMD wave
```

### WiFi Channel Configuration

Both boards must use the same ESP-NOW channel. The default is channel 1.

To avoid interference with your local WiFi router:
- If your router uses channel 1 → set ESP-NOW to channel 6 or 11
- If your router uses channel 6 → set ESP-NOW to channel 1 or 11
- If your router uses channel 11 → set ESP-NOW to channel 1 or 6

**On the controller** (persisted to flash):
```
CHANNEL 6
```
Then restart the controller.

**On the robot**, change `ESPNOW_CHANNEL` in `espnow-protocol.h`:
```cpp
#define ESPNOW_CHANNEL 6
```
Then reflash the robot.

Use the `WiFi_Channel_Scanner` sketch to find which channels are in use near you.

## Serial Command Reference

All commands are text, one per line, newline terminated (`\n`). Connect to the ESP32-C3 controller at 115200 baud.

### Motion Commands

| Command | Description |
|---|---|
| `CMD forward` | Walk forward |
| `CMD backward` | Walk backward |
| `CMD left` | Turn left |
| `CMD right` | Turn right |
| `CMD rest` | Rest position (all servos 90°) |
| `CMD stand` | Standing pose |
| `CMD wave` | Wave animation |
| `CMD dance` | Dance animation |
| `CMD swim` | Swim animation |
| `CMD point` | Point forward |
| `CMD pushup` | Push-up animation |
| `CMD bow` | Bow animation |
| `CMD cute` | Cute pose |
| `CMD freaky` | Freaky animation |
| `CMD worm` | Worm animation |
| `CMD shake` | Shake animation |
| `CMD shrug` | Shrug animation |
| `CMD dead` | Play dead |
| `CMD crab` | Crab walk |
| `STOP` | Stop current motion |

### Face Commands

| Command | Description |
|---|---|
| `FACE happy` | Happy expression |
| `FACE sad` | Sad expression |
| `FACE angry` | Angry expression |
| `FACE surprised` | Surprised expression |
| `FACE sleepy` | Sleepy expression |
| `FACE love` | Love expression |
| `FACE excited` | Excited expression |
| `FACE confused` | Confused expression |
| `FACE thinking` | Thinking expression |
| `FACE idle` | Idle with blink animation |
| `FACE default` | Default face |
| `FACE talk_happy` | Talking happy (for speech sync) |
| `FACE talk_sad` | Talking sad |
| ... | (all emotions have `talk_` variants) |

### Servo Control

| Command | Description |
|---|---|
| `SERVO <ch> <angle>` | Set servo channel (0-7) to angle (0-180) |
| `SERVO_ALL <angle>` | Set all servos to same angle |

**Channel mapping:**

| Channel | Name | Position |
|---|---|---|
| 0 | R1 | Right front hip |
| 1 | R2 | Right rear hip |
| 2 | L1 | Left front hip |
| 3 | L2 | Left rear hip |
| 4 | R4 | Right rear knee |
| 5 | R3 | Right front knee |
| 6 | L3 | Left front knee |
| 7 | L4 | Left rear knee |

### Servo Trimming

| Command | Description |
|---|---|
| `TRIM_SET <ch> <val>` | Set subtrim for channel (0-7), value -90 to +90 |
| `TRIM_GET` | Get all current subtrim values |
| `TRIM_RESET` | Reset all trims to 0 |

### Configuration

| Command | Description |
|---|---|
| `CONFIG_SET frameDelay <ms>` | Delay between animation frames (default: 100) |
| `CONFIG_SET walkCycles <n>` | Walk cycles per command (default: 10) |
| `CONFIG_SET motorCurrentDelay <ms>` | Delay between servo moves (default: 40) |
| `CONFIG_SET faceFps <n>` | Face animation FPS (default: 8) |
| `CONFIG_SET sensorMode <n>` | Sensor mode: 0=off, 1=accel, 2=gyro, 3=magneto, 4=rpy |
| `CONFIG_SET sensorRate <ms>` | Sensor update rate in ms (0=off) |
| `CONFIG_GET` | Get all config values |

### Sensor Commands

| Command | Description |
|---|---|
| `PING` | `PONG rtt=<ms>` | Round-trip latency |
| `STATUS` | `STATUS cmd=<motion> face=<name>` | Current robot state |

### System Commands

| Command | Response | Description |
|---|---|---|
| `MAC` | `MAC <aa:bb:cc:dd:ee:ff>` | Controller MAC address |
| `CHANNEL [n]` | `CHANNEL <n>` | Get/set ESP-NOW channel |
| `SET_ROBOT_MAC <mac>` | `OK ...` | Set robot MAC (persisted) |
| `HELP` | (help text) | Show all commands |

### Response Format

| Response | Meaning |
|---|---|
| `OK` | Command acknowledged by robot |
| `OK SENT` | Command sent, awaiting robot acknowledgement |
| `ERR <message>` | Error with description |
| `TRIM <v0> ... <v7>` | Subtrim values for all 8 servos |
| `CONFIG frameDelay=... walkCycles=... motorCurrentDelay=... faceFps=... sensorMode=... sensorRate=...` | All config values |
| `STATUS cmd=... face=...` | Robot status |
| `PONG rtt=<ms>` | Round-trip time |
| `SENSOR mode=<n> ax=... ay=... az=... gx=... gy=... gz=... mx=... my=... mz=... roll=... pitch=... yaw=...` | MPU6050 sensor data |

## ESP-NOW Binary Protocol

For developers building custom controllers or extending the protocol.

### Message Format

Every ESP-NOW message starts with a 2-byte header:

```
Byte 0: msg_type (uint8)
Byte 1: msg_id   (uint8, sequence number 0-255)
Remaining: payload (type-specific)
```

Maximum ESP-NOW payload is 250 bytes.

### Command Messages (Controller → Robot)

| Type | Hex | Struct | Payload |
|---|-----|---|---|
| Motion | `0x01` | `sesame_motion_cmd_t` | `char[16]` command name |
| Face | `0x02` | `sesame_face_cmd_t` | `char[24]` face name |
| Stop | `0x03` | (header only) | — |
| Servo Set | `0x04` | `sesame_servo_set_t` | `uint8 channel, uint8 angle` |
| Servo All | `0x05` | `sesame_servo_all_t` | `uint8 angle` |
| Trim Set | `0x06` | `sesame_trim_set_t` | `uint8 channel, int8 value` |
| Trim Get | `0x07` | (header only) | — |
| Trim Reset | `0x08` | (header only) | — |
| Config Set | `0x09` | `sesame_config_set_t` | `uint8 key, int16 value` |
| Config Get | `0x0A` | (header only) | — |
| Status Get | `0x0B` | (header only) | — |
| Ping | `0x0C` | `sesame_ping_t` | `uint32 timestamp_us` |

### Response Messages (Robot → Controller)

| Type | Hex | Struct | Payload |
|---|-----|---|---|
| ACK | `0x80` | `sesame_ack_t` | `uint8 orig_msg_id, uint8 status` |
| Trim Data | `0x81` | `sesame_trim_data_t` | `int8[8]` subtrim values |
| Config Data | `0x82` | `sesame_config_data_t` | `int16 × 4` config values |
| Status Data | `0x83` | `sesame_status_data_t` | `char[16] + char[24]` cmd + face |
| Pong | `0x84` | `sesame_pong_t` | `uint32 × 2` timestamps |
| Sensor Data | `0x85` | `sesame_sensor_data_t` | `float × 6 + uint32` (future: MPU6050) |

### ACK Status Codes

| Code | Hex | Meaning |
|---|-----|---|
| OK | `0x00` | Success |
| Error | `0x01` | General error |
| Unknown | `0x02` | Unknown command type |
| Invalid | `0x03` | Invalid parameters |

### Config Keys

| Key | Hex | Parameter |
|-----|-----|---|
| `0x01` | Frame delay | `frameDelay` (ms) |
| `0x02` | Walk cycles | `walkCycles` (count) |
| `0x03` | Motor current delay | `motorCurrentDelay` (ms) |
| `0x04` | Face FPS | `faceFps` (Hz) |

All struct definitions are in `software/esp-now/espnow-protocol.h`. Include this header in any custom firmware to use the protocol.

## Python Example

Control the robot from Python via the controller's serial port:

```python
import serial
import time

# Connect to the ESP32-C3 controller
ser = serial.Serial('/dev/ttyUSB0', 115200, timeout=2)
time.sleep(2)  # Wait for boot

def send(cmd):
    """Send command and print response."""
    ser.write(f"{cmd}\n".encode())
    time.sleep(0.1)
    while ser.in_waiting:
        print(ser.readline().decode().strip())

# Test connection
send("PING")

# Play a motion
send("CMD wave")
time.sleep(5)

# Set a face
send("FACE happy")

# Direct servo control
send("SERVO 0 135")   # R1 to 135 degrees

# Read trims
send("TRIM_GET")

# Set a trim
send("TRIM_SET 0 5")  # +5 degree offset on R1

# Get robot status
send("STATUS")

ser.close()
```

On Raspberry Pi, the serial port is typically `/dev/ttyUSB0` or `/dev/ttyACM0`.

## Troubleshooting

### No response to PING

1. **Check MAC address**: Run `MAC` on the controller to verify its address. The robot prints its MAC at boot in the serial monitor.
2. **Check channel**: Both must use the same `ESPNOW_CHANNEL`. Default is 1.
3. **Check distance**: Start with boards < 1 meter apart.
4. **Check power**: Both boards need adequate power (USB or battery).
5. **Re-set robot MAC**: `SET_ROBOT_MAC <robot_mac>` on the controller.

### Robot not responding to commands

1. **Check robot serial monitor**: The robot prints `[ESP-NOW] Motion: wave` etc. when it receives commands. If you see nothing, ESP-NOW isn't reaching it.
2. **Auto-registration**: The robot auto-registers the controller on the first received message. If the controller MAC changes, restart the robot.
3. **Verify firmware**: Make sure the robot is running `sesame-firmware-espnow.ino`, not the WiFi version.

### High latency (>10ms)

1. **Channel interference**: Use `WiFi_Channel_Scanner` to find a clear channel.
2. **Distance**: ESP-NOW latency increases slightly with distance.
3. **Other 2.4GHz devices**: Bluetooth, microwaves, and other WiFi networks can interfere.

### Servo jitter or incorrect angles

1. Use `TRIM_SET` to calibrate each servo.
2. Check `motorCurrentDelay` — too low can cause power brownouts: `CONFIG_SET motorCurrentDelay 40`
3. Ensure adequate power supply for the servo rail.

### Robot serial debug

The robot still accepts direct serial commands for debugging. Connect a serial monitor to the robot's USB port and type `help`:

```
=== Serial Debug Commands ===
  <motor 0-7> <angle 0-180>  Set servo
  all <angle>                Set all servos
  rn wf/wb/tl/tr             Walk/turn
  rn rs/st/wv/dn/sw/pt       Poses
  mac                         Show MAC address
  subtrim / st                Show trims
  help                        This help
```

## File Reference

| File | Description |
|---|---|
| `software/esp-now/espnow-protocol.h` | Shared protocol definitions (include in both firmwares) |
| `software/esp-now/ESP32_C3_Sesame/ESP32_C3_Sesame.ino` | Controller firmware (ESP32-C3) |
| `firmware/sesame-firmware-espnow.ino` | Robot firmware, ESP-NOW version (ESP32-S3) |
| `firmware/sesame-firmware-main.ino` | Robot firmware, original WiFi version (unchanged) |
| `firmware/face-bitmaps.h` | OLED face bitmap data (shared by both firmware versions) |
| `firmware/movement-sequences.h` | Servo movement sequences (shared by both firmware versions) |
| `software/esp-now/WiFi_Channel_Scanner/` | Utility to scan WiFi channels |

## Differences from WiFi Firmware

| Feature | WiFi (`sesame-firmware-main.ino`) | ESP-NOW (`sesame-firmware-espnow.ino`) |
|---|---|---|
| Control method | WiFi AP + WebServer + captive portal | ESP-NOW radio (no WiFi AP) |
| Latency | 20-100ms (HTTP) | 1-5ms |
| Range | WiFi range (~30m indoor) | ESP-NOW range (~100m line of sight) |
| UI | Built-in web controller | External (serial terminal, Python, etc.) |
| Dependencies | WiFi, WebServer, DNSServer, ESPmDNS | WiFi (STA mode only), esp_now |
| Power | Higher (WiFi AP active) | Lower (no AP, no HTTP stack) |
| Serial debug CLI | Yes | Yes (identical commands) |
| Servo/face/motion code | Identical | Identical |
| NVS storage | Identical | Identical |

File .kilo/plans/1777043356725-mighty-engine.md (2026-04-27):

# Plan: Add Servo Subtrim UI to Captive Portal

## Summary
Add a new "Trims" section to the web UI that allows users to adjust servo subtrim values (+/-) for each of the 8 servos (L1, L2, L3, L4, R1, R2, R3, R4) and save them persistently.

## Current State
- Subtrim values are stored in `int8_t servoSubtrim[8]` (line 76 of `.ino`)
- Subtrim is applied in `setServoAngle()` (line 571-577): `constrain(angle + servoSubtrim[channel], 0, 180)`
- Serial CLI has subtrim commands but no web access
- The `/getSettings` endpoint returns settings as JSON but does not include subtrim
- Motor labels in the UI: S0=R1, S1=R2, S2=L1, S3=L2, S4=R4, S5=R3, S6=L3, S7=L4

## Implementation Steps

### 1. Add Backend Endpoints in `sesame-firmware-main.ino`

#### 1a. Add `/getSubtrim` endpoint
- Create `handleGetSubtrim()` function
- Return JSON array of 8 subtrim values: `{"subtrim":[0,0,0,0,0,0,0,0]}`
- Register in `setup()`: `server.on("/getSubtrim", handleGetSubtrim);`

#### 1b. Add `/setSubtrim` endpoint  
- Create `handleSetSubtrim()` function
- Accept query params: `motor` (1-8) and `value` (-90 to 90)
- Update `servoSubtrim[motor-1]` with the value
- Apply immediately to the servo if currently attached by calling `setServoAngle()` with the current position
- Return 200 OK on success, 400 on invalid input
- Register in `setup()`: `server.on("/setSubtrim", handleSetSubtrim);`

#### 1c. Add `/resetSubtrim` endpoint
- Create `handleResetSubtrim()` function
- Reset all `servoSubtrim` values to 0
- Return 200 OK
- Register in `setup()`: `server.on("/resetSubtrim", handleResetSubtrim);`

### 2. Add UI Section in `captive-portal.h`

#### 2a. Add Trims Section HTML
Add a new section in the desktop right column (after the System section):
```html
<div class="section">
  <div class="section-title">Trims</div>
  <div class="trim-grid">
    <!-- L1 -->
    <div class="trim-row">
      <span class="trim-label">L1</span>
      <button class="btn-trim-minus" onclick="adjustTrim(3, -1)">-</button>
      <span class="trim-value" id="trim3">0</span>
      <button class="btn-trim-plus" onclick="adjustTrim(3, 1)">+</button>
    </div>
    <!-- L2 -->
    <div class="trim-row">
      <span class="trim-label">L2</span>
      <button class="btn-trim-minus" onclick="adjustTrim(4, -1)">-</button>
      <span class="trim-value" id="trim4">0</span>
      <button class="btn-trim-plus" onclick="adjustTrim(4, 1)">+</button>
    </div>
    <!-- L3 -->
    <div class="trim-row">
      <span class="trim-label">L3</span>
      <button class="btn-trim-minus" onclick="adjustTrim(7, -1)">-</button>
      <span class="trim-value" id="trim7">0</span>
      <button class="btn-trim-plus" onclick="adjustTrim(7, 1)">+</button>
    </div>
    <!-- L4 -->
    <div class="trim-row">
      <span class="trim-label">L4</span>
      <button class="btn-trim-minus" onclick="adjustTrim(8, -1)">-</button>
      <span class="trim-value" id="trim8">0</span>
      <button class="btn-trim-plus" onclick="adjustTrim(8, 1)">+</button>
    </div>
    <!-- R1 -->
    <div class="trim-row">
      <span class="trim-label">R1</span>
      <button class="btn-trim-minus" onclick="adjustTrim(1, -1)">-</button>
      <span class="trim-value" id="trim1">0</span>
      <button class="btn-trim-plus" onclick="adjustTrim(1, 1)">+</button>
    </div>
    <!-- R2 -->
    <div class="trim-row">
      <span class="trim-label">R2</span>
      <button class="btn-trim-minus" onclick="adjustTrim(2, -1)">-</button>
      <span class="trim-value" id="trim2">0</span>
      <button class="btn-trim-plus" onclick="adjustTrim(2, 1)">+</button>
    </div>
    <!-- R3 -->
    <div class="trim-row">
      <span class="trim-label">R3</span>
      <button class="btn-trim-minus" onclick="adjustTrim(6, -1)">-</button>
      <span class="trim-value" id="trim6">0</span>
      <button class="btn-trim-plus" onclick="adjustTrim(6, 1)">+</button>
    </div>
    <!-- R4 -->
    <div class="trim-row">
      <span class="trim-label">R4</span>
      <button class="btn-trim-minus" onclick="adjustTrim(5, -1)">-</button>
      <span class="trim-value" id="trim5">0</span>
      <button class="btn-trim-plus" onclick="adjustTrim(5, 1)">+</button>
    </div>
  </div>
  <div style="margin-top: 15px; display: flex; gap: 10px;">
    <button class="btn-save-trims" onclick="saveTrims()" style="flex:1;">Save Trims</button>
    <button class="btn-reset-trims" onclick="resetTrims()" style="flex:1;">Reset</button>
  </div>
</div>
```

**Motor Mapping Note:** The UI shows motor numbers 1-8 matching the slider labels:
- S0 R1 = Motor 1, S1 R2 = Motor 2, S2 L1 = Motor 3, S3 L2 = Motor 4
- S4 R4 = Motor 5, S5 R3 = Motor 6, S6 L3 = Motor 7, S7 L4 = Motor 8

Order in the UI (grouped by side): L1(3), L2(4), L3(7), L4(8), R1(1), R2(2), R3(6), R4(5)

#### 2b. Add CSS Styles for Trims Section
```css
.trim-grid {
  display: grid;
  grid-template-columns: 1fr;
  gap: 8px;
}
.trim-row {
  display: flex;
  align-items: center;
  justify-content: space-between;
  background: rgba(0,0,0,0.2);
  padding: 8px 12px;
  border-radius: 8px;
}
.trim-label {
  font-size: 14px;
  font-weight: 600;
  color: #fff;
  width: 30px;
}
.trim-value {
  font-size: 14px;
  color: var(--content-color);
  width: 35px;
  text-align: center;
  font-weight: 600;
}
.btn-trim-minus, .btn-trim-plus {
  width: 36px;
  height: 36px;
  padding: 0;
  font-size: 20px;
  font-weight: bold;
  border-radius: 8px;
}
.btn-trim-minus {
  background: linear-gradient(145deg, #e74c3c, #c0392b);
  color: #fff;
}
.btn-trim-plus {
  background: linear-gradient(145deg, #2ecc71, #27ae60);
  color: #fff;
}
.btn-save-trims {
  background: linear-gradient(145deg, var(--content-color), var(--content-color-dark));
  color: #fff;
  padding: 12px;
  font-size: 14px;
  border-radius: 8px;
}
.btn-reset-trims {
  background: linear-gradient(145deg, #555, #444);
  color: #fff;
  padding: 12px;
  font-size: 14px;
  border-radius: 8px;
}
```

#### 2c. Add JavaScript Functions
```javascript
// Load subtrim values when page loads
function loadSubtrim() {
  fetch('/getSubtrim').then(r => r.json()).then(data => {
    for (let i = 1; i <= 8; i++) {
      const el = document.getElementById('trim' + i);
      if (el) {
        el.textContent = data.subtrim[i-1];
        updateTrimColor(el, data.subtrim[i-1]);
      }
    }
  }).catch(console.log);
}

function updateTrimColor(el, value) {
  if (value > 0) el.style.color = '#2ecc71';
  else if (value < 0) el.style.color = '#e74c3c';
  else el.style.color = 'var(--content-color)';
}

function adjustTrim(motorNum, delta) {
  const el = document.getElementById('trim' + motorNum);
  if (!el) return;
  let currentValue = parseInt(el.textContent);
  let newValue = currentValue + delta;
  // Clamp to -90 to 90
  newValue = Math.max(-90, Math.min(90, newValue));
  el.textContent = newValue;
  updateTrimColor(el, newValue);
  // Send to firmware immediately
  fetch(`/setSubtrim?motor=${motorNum}&value=${newValue}`).catch(console.log);
}

function saveTrims() {
  // Save is immediate - just confirm to user
  alert('Trims saved! Values are applied immediately.');
}

function resetTrims() {
  if (!confirm('Reset all trim values to 0?')) return;
  fetch('/resetSubtrim').then(() => {
    for (let i = 1; i <= 8; i++) {
      const el = document.getElementById('trim' + i);
      if (el) {
        el.textContent = '0';
        updateTrimColor(el, 0);
      }
    }
  }).catch(console.log);
}

// Add loadSubtrim to DOMContentLoaded
document.addEventListener('DOMContentLoaded', () => {
  loadTheme();
  loadSubtrim();
});
```

### 3. Desktop Layout Adjustment
In the `@media (min-width: 1024px)` section, the right column currently has only the System section. Add the Trims section to the right column's section-column div.

## Files to Modify
1. `firmware/sesame-firmware-main.ino` - Add 3 new endpoint handlers and registrations
2. `firmware/captive-portal.h` - Add HTML section, CSS styles, and JavaScript functions

## Key Design Decisions
1. **Immediate apply**: Each +/- button press sends the value to firmware immediately, so the user can see the servo move in real-time
2. **"Save Trims" is informational**: Values are already applied immediately, the button provides user feedback
3. **Reset option**: Quick reset button to zero all trims
4. **Color feedback**: Positive values show green, negative show red, zero shows theme color
5. **Range**: -90 to +90 degrees, matching the serial CLI constraints
6. **Motor numbering**: Uses 1-8 to match the existing manual motor control UI

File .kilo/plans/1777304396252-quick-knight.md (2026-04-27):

# Plan: Convert Sesame Robot to ESP-NOW Protocol

## Overview

Convert the Sesame robot from WiFi/WebServer-based control to ESP-NOW protocol. Create a new ESP32-C3 controller (`ESP32_C3_Sesame`) that bridges a computer/Raspberry Pi (via USB serial) to the robot (via ESP-NOW).

**Robot board:** ESP32-S3  
**Controller board:** ESP32-C3 Mini  
**WiFi removal:** Complete (no compile-time option)  
**Serial CLI:** Kept on robot for debugging  

---

## Architecture

```
┌─────────────┐    USB Serial     ┌─────────────────┐    ESP-NOW     ┌──────────────┐
│  Computer/  │ ←──(text cmds)──→ │  ESP32-C3 Mini  │ ←──(binary)──→ │  ESP32-S3    │
│  Raspberry  │                   │  (Controller)   │               │  (Robot)     │
│  Pi         │                   │  ESP32_C3_Sesame│               │  8 Servos    │
│             │                   │                 │               │  OLED Face   │
└─────────────┘                   └─────────────────┘               │  (MPU6050*)  │
                                                                    └──────────────┘
                                                            * Future sensor integration
```

---

## ESP-NOW Binary Protocol

### Message Format (max 250 bytes)

```
[1 byte: msg_type] [1 byte: msg_id] [N bytes: payload]
```

- `msg_type`: Command/response type (see tables below)
- `msg_id`: Sequence number (0-255, wraps). Used to match responses to requests.
- `payload`: Type-specific data

### Command Messages (Controller → Robot)

| Type | Hex  | Name | Payload | Description |
|---|---|---|---|---|
| 0x01 | CMD  | MOTION_CMD | Null-terminated string (max 16 chars) | Play motion (e.g. "forward", "wave") |
| 0x02 | FACE | FACE_CMD | Null-terminated string (max 20 chars) | Set face (e.g. "happy", "idle") |
| 0x03 | STOP | STOP_CMD | (none) | Stop current motion |
| 0x04 | SSET | SERVO_SET | `[uint8 channel, uint8 angle]` (2 bytes) | Set single servo angle (0-180) |
| 0x05 | SALL | SERVO_ALL | `[uint8 angle]` (1 byte) | Set all servos to same angle |
| 0x06 | TSET | TRIM_SET | `[uint8 channel, int8 value]` (2 bytes) | Set subtrim for one servo |
| 0x07 | TGET | TRIM_GET | (none) | Request all subtrim values |
| 0x08 | TRST | TRIM_RESET | (none) | Reset all subtrims to 0 |
| 0x09 | CSET | CONFIG_SET | `[uint8 key, int16 value]` (3 bytes) | Set a config parameter |
| 0x0A | CGET | CONFIG_GET | (none) | Request all config values |
| 0x0B | STAT | STATUS_GET | (none) | Request robot status |
| 0x0C | PING | PING | `[uint32 timestamp_us]` (4 bytes) | Latency measurement |

**Config keys for CONFIG_SET (0x09):**
- `0x01` = frameDelay
- `0x02` = walkCycles
- `0x03` = motorCurrentDelay
- `0x04` = faceFps

### Response Messages (Robot → Controller)

| Type | Hex  | Name | Payload | Description |
|---|---|---|---|---|
| 0x80 | ACK  | ACK | `[uint8 orig_msg_id, uint8 status]` (2 bytes) | 0=OK, 1=ERR |
| 0x81 | TDAT | TRIM_DATA | `[int8 × 8]` (8 bytes) | All subtrim values |
| 0x82 | CDAT | CONFIG_DATA | `[int16 × 4]` (8 bytes) | frameDelay, walkCycles, mcd, fps |
| 0x83 | SDAT | STATUS_DATA | `[16 char cmd, 20 char face]` (36 bytes) | Current command + face name |
| 0x84 | PONG | PONG | `[uint32 orig_timestamp, uint32 robot_time]` (8B)  | Ping response |
| 0x85 | SENS | SENSOR_DATA | `[float ax, ay, az, uint32 ts]` (16 bytes) | Future: MPU6050 data |

### Shared Header File

Create `espnow-protocol.h` to be included by both Controller and Robot firmware, containing:
- All struct definitions
- Message type constants
- Common utilities

---

## Serial Protocol (Computer ↔ ESP32-C3)

Text-based, one command per line, `\n` terminated.

### Commands (Computer → Controller)

```
CMD <motion>           # e.g. CMD forward, CMD wave, CMD rest
STOP                   # Stop current motion
FACE <name>            # e.g. FACE happy, FACE idle
SERVO <ch> <angle>     # e.g. SERVO 0 90 (channel 0-7, angle 0-180)
SERVO_ALL <angle>      # Set all servos to angle
TRIM_SET <ch> <val>    # e.g. TRIM_SET 0 5 (channel 0-7, value -90..90)
TRIM_GET               # Request subtrim values
TRIM_RESET             # Reset all trims
CONFIG_SET <key> <val> # e.g. CONFIG_SET frameDelay 100
CONFIG_GET             # Request config values
STATUS                 # Request robot status
PING                   # Measure round-trip latency
MAC                    # Print controller's MAC address
CHANNEL <n>            # Set ESP-NOW channel (1-13)
```
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

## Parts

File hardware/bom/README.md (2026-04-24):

# Bill of Materials

Every part required to assemble Sesame is cataloged here. Pick the wiring strategy that fits your parts bin, then follow the build flow in [docs/build-guide/README.md](../../docs/build-guide/README.md).

> [!NOTE]
> Amazon links below point to representative search results so you can choose local suppliers or equivalent listings. Pricing and availability change frequently. If you don't mind waiting shipping times you can also order direct from manufacturer for much lower rates.

## Core Electronics (Both Builds)

| Item | Qty | Notes | Source |
| --- | --- | --- | --- |
| MG90S all-metal micro servos | 8 (buy 10 for spares) | Primary hip/leg actuators; includes servo horns but keep extras | [Amazon](https://www.amazon.com/s?k=mg90s+metal+gear+servo+pack+of+8) |
| 0.96" SSD1306 I2C OLED | 1 | 128x64 display that slides into the top cover slot | [Amazon](https://www.amazon.com/s?k=0.96%22+I2C+OLED+SSD1306) |
| USB-C data/power cable | 1 | Needs to carry 5V/3A for flashing and tethered mode | [Amazon](https://www.amazon.com/s?k=usb+c+cable+60w) |
| Rocker power switch (KCD1, panel mount) | 1 | Snaps into the top cover cutout | [Amazon](https://www.amazon.com/s?k=KCD1+mini+rocker+switch+2+pin) |
| 22AWG silicone wire kit | 1 | Power/ground bus lines | [Amazon](https://www.amazon.com/s?k=22awg+silicone+wire+kit) |
| 30AWG silicone wire kit | 1 | Signal leads and dense harnessing | [Amazon](https://www.amazon.com/s?k=30awg+silicone+wire) |
| Heat-shrink assortment | 1 | Insulate OLED, switch, and battery joints | [Amazon](https://www.amazon.com/s?k=heat+shrink+tubing+kit) |
| Small zip ties | 1 pack | Bundling wires inside the frame | [Amazon](https://www.amazon.com/s?k=mini+zip+ties) |

## Wiring Option A – S2 Mini / Hand-Wired Harness

| Item | Qty | Notes | Source |
| --- | --- | --- | --- |
| Lolin/WeMos ESP32-S2 Mini | 1 | Native USB-C, fits on perfboard for the hand-wired build | [Amazon](https://www.amazon.com/s?k=esp32+s2+mini) |
| Small protoboard (approx. 5×7 cm) | 1 | Hosts the header matrix and rails | [Amazon](https://www.amazon.com/s?k=prototype+perfboard) |
| 3-pin male headers | 8 | Build the servo breakout; match spacing to MG90 plugs | [Amazon](https://www.amazon.com/s?k=pin+header+strip) |
| Buck converter (5–12 V in to stable 5V/3A out) | 1 | Powers motors + MCU when using batteries | [Amazon](https://www.amazon.com/s?k=3a+dc+dc+buck+converter+module) |

## Wiring Option B – Sesame Distro Board V2 (Included in Build Kits)

> [!NOTE]
> If you purchased a Sesame Build Kit, your V2 Distro Board is already assembled, pre-flashed, and included. You don't need to order these parts separately.

| Item | Qty | Notes | Source |
| --- | --- | --- | --- |
| Sesame Distro Board V2 PCB | 1 | Fully SMD design. Order with PCBway assembly service or attempt advanced hand soldering. See [ordering guide](/hardware/pcb/README.md) | [GitHub](/hardware/pcb/README.md) |

## Wiring Option C – Sesame Distro Board V1 / ESP32-DevKitC-32E (Legacy)

> [!CAUTION]
> V1 is now phased out but still supported. Only choose this if you already have a V1 board.

| Item | Qty | Notes | Source |
| --- | --- | --- | --- |
| ESP32-DevKitC-32E (ESP32-WROOM-32) | 1 | Base board the Distro Board V1 stacks on. This one is very tricky because its a very specific board. You can use the 32E with the floating pcb antenna OR you can use the 32U but you have to route an antenna inside. | [Amazon](https://www.amazon.com/s?k=ESP32+DevKitC+32) |
| Sesame Distro Board V1 PCB | 1 | Order `Gerber_Sesame-Distro-Board_PCB_Sesame-Distro-Board_V1.zip` via PCBway | [GitHub](/hardware/pcb/README.md) |
| 5V buck converter (same spec as above) | 1 | Mounts on the distro board pads | [Amazon](https://www.amazon.com/s?k=3a+dc+dc+buck+converter+module) |
| 1000 µF electrolytic capacitor | 1 | Smooths output voltage on buck converter; 10V+ rating recommended | [Amazon](https://www.amazon.com/s?k=1000uf+electrolytic+capacitor) |
| 4-pin JST-XH or PH header | 1 | Optional external connector footprint on PCB | [Amazon](https://www.amazon.com/s?k=jst+xh+4+pin+kit) |
| 2-pin screw terminal (2.54 mm pitch) | 1 | Optional battery input on PCB | [Amazon](https://www.amazon.com/s?k=2+pin+screw+terminal+block+2.54mm+pitch) |
| M2.5 × 5 mm male-female standoffs | 4 | Elevate the PCB over the DevKit mounting holes | [Amazon](https://www.amazon.com/s?k=m2.5+male+female+standoff+5mm) |

## Power Sources & Connectors

| Item | Qty | Notes | Source |
| --- | --- | --- | --- |
| 3S 450 mAh LiPo with XT30 | 1 | Recommended wireless pack; ensure high-discharge rating | [Amazon](https://www.amazon.com/s?k=3s+450mah+lipo+xt30) |
| 2× AAA holder | 1 set | 2S pack using AAA size Li-Ion Batteries (~7.4 V nominal) that fits the chassis battery slot; use a buck converter | [Amazon](https://www.amazon.com/s?k=2x+aaa+battery+holder) |
| 10440 Li-ion cells (350–400 mAh typical) | 2 | Standard 10×44 mm Li-ion cells; buy spares | [Amazon](https://www.amazon.com/s?k=10440+li-ion+cell+350mah) |
| 2-slot 10440 Li-ion charger | 1 | Charge cells outside the holder; avoid in-holder charging unless the holder is designed for it | [Amazon](https://www.amazon.com/s?k=10440+li-ion+charger+2+slot) |
| XT30 female pigtail | 1 | Interface battery to switch/PCB without cutting stock leads | [Amazon](https://www.amazon.com/s?k=xt30+female+pigtail) |

## Fasteners & Mechanical Hardware

| Item | Qty | Usage | Amazon |
| --- | --- | --- | --- |
| M2 × 5 mm self-threading screws | ~40 | All plastic joints, OLED retention, motor mounts, and covers (Can just get a variety pack) | [Amazon](https://www.amazon.com/s?k=m2+self+tapping+screws+kit) |
| M2.5 × 5mm machine screws | 10 | Servo horn attachment to servo shafts only. Included servo horn screws are usually too short. | [Amazon](https://www.amazon.com/s?k=m2+machine+screw+kit) |

## 3D Printed Parts

Print the 11-part part set outlined in [printing/README.md](../printing/README.md). STL and CAD sources live under `hardware/printing/`.

## Consumables & Tools Checklist

| Item | Notes | Source |
| --- | --- | --- |
| Leaded solder (0.6–0.8 mm) | Easier flow for dense perfboard work | [Amazon](https://www.amazon.com/s?k=63%2F37+solder+0.8mm) |
| Flux pen | Protects pads on the perfboard and PCB | [Amazon](https://www.amazon.com/s?k=flux+pen) |
| Solder wick / pump | For rework on the OLED pins | [Amazon](https://www.amazon.com/s?k=solder+wick) |
| Small flush cutters | Trim servo leads, perfboard traces, or supports | [Amazon](https://www.amazon.com/s?k=flush+cutters) |
| Precision screwdriver set | Needed for self-tapping M2 hardware | [Amazon](https://www.amazon.com/s?k=precision+screwdriver+set) |

## Power & Safety Notes

- Sesame needs at least 5 V at 3 A available at the rails. 
- **Lolin S2 Mini:** Can be powered via USB-C PD (5V/3A capable) for tethered operation, or via battery + buck converter.
- **Distro Board V2:** Supports both USB-C PD (5V/3A) for tethered operation AND battery + buck converter. Included in all Sesame Build Kits.
- **Distro Board V1 (Legacy):** Cannot run on tethered USB-C power due to design limitations. Must use battery + buck converter for operation.
- When battery powering either build, route the pack through the rocker switch and buck converter before it touches the rails, mirroring the schematic in [docs/wiring-guide/README.md](../../docs/wiring-guide/README.md).
- **Never cut the factory battery connector off the pack.** Instead, create adapter pigtails using XT30 or JST RCY leads so the pack remains chargeable.
- A 2× 10440 Li-ion + 2× AAA holder pack fits the stock battery cavity and works well with the existing power switch + buck converter.
- **Always remove and charge 10440 cells separately in a proper Li-ion charger.** Do not charge them while inside the AAA holder unless the holder explicitly supports safe Li-ion charging (most do not).

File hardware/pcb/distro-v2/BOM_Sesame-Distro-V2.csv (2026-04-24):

ID | Name | Designator | Footprint | Quantity | Manufacturer Part | Manufacturer | Supplier | Supplier Part | Price
1 | 22nF | C3,C9,C11 | C0603 | 3 | CL10B223KB8NNNC | SAMSUNG(三星) | LCSC | C21122 | 0.004
2 | 100nF | C4,C8,C10 | C0603 | 3 | CC0603KRX7R9BB104 | YAGEO(国巨) | LCSC | C14663 | 0.002
3 | 10nF | C5 | C0603 | 1 | C0603B103M500NT | TORCH(火炬) | LCSC | C17702744 | 0.005
4 | 3.3uH | L1 | IND-SMD_L7.3-W6.6 | 1 | MHCI06030-3R3M-S8 | Chilisin(奇力新) | LCSC | C285713 | 0.147
5 | KT-0603R | LED1 | LED0603-RD | 1 | KT-0603R | KENTO | LCSC | C2286 | 0.007
6 | 5.1kΩ | R1,R5 | R0603 | 2 | 0603WAF5101T5E | UNI-ROYAL(厚声) | LCSC | C23186 | 0.001
7 | 56kΩ | R2 | R0603 | 1 | 0603WAF5602T5E | UNI-ROYAL(厚声) | LCSC | C23206 | 0.001
8 | 10kΩ | R3,R4,R8,R9 | R0603 | 4 | RCT0310KJLF | HKR(香港电阻) | LCSC | C177337
9 | 3.5MM-2PIN | 5-12V | SCREWTERM-3.5MM-2PIN | 1 | XY302V-3.5-2P | XY | LCSC | C784940
10 | B4B-XH-A(LF)(SN) | JST-XH | JST-XH-4PIN-2.5 | 1 | B4B-XH-A(LF)(SN) | JST | LCSC | C144395
11 | HX 3X4X2-2P-1.6N TACTILE SWITCH | RESET,BOOT | KEY-SMD_L4.0-W3.0-LS4.9-1 | 2 | HX 3x4x2-2P-1.6N TACTILE SWITCH | hanxia(韩下) | LCSC | C49234124 | 0.02
12 | SolderPad (No Part Required) | U5,U7 | SOLDERPAD LG | 2
13 | 1uF | C1 | C0805 | 1 | AC0805KKX7R9BB105 | YAGEO(国巨) | LCSC | C726584 | 0.035
14 | 470uF | C7 | CAP-SMD_BD10.0-L10.3-W10.3-LS11.3-FD | 1 | XT470UF25V90RV0111 | KNSCHA(科尼盛) | LCSC | C3445244 | 0.128
15 | SS34_C8678 | D1,D2 | SMA_L4.3-W2.6-LS5.2-RD | 2 | SS34 | MDD(辰达半导体) | LCSC | C8678 | 0.03
16 | 3PIN MALE HEADER | P1,P2,P3,P4,P5,P6,P7,P8 | CONNECTOR_PINHEADER_2.54MM:PINHEADER_1X3 | 8 | Male headerHDR1X3-2.54 | BOOMELE | LCSC | C49257 | 0.088
17 | ESP32-S3-WROOM-1(N16R8) | U1 | WIRELM-SMD_ESP32-S3-WROOM-1 | 1 | ESP32-S3-WROOM-1-N16R8 | ESPRESSIF(乐鑫) | LCSC | C2913202 | 5.613
18 | AMS1117-3.3 | U2 | SOT-223-3_L6.5-W3.4-P2.30-LS7.0-BR | 1 | AMS1117-3.3 | AMS | LCSC | C6186 | 0.197
19 | MSTPS563200DDCR | U3BUCK | SOT-23-6_L2.9-W1.6-P0.95-LS2.8-BR | 1 | MSTPS563200DDCR | MSKSEMI(美森科) | LCSC | C49208508 | 0.177
20 | 10uF | U4 | CAP-SMD_BD4.0-L4.3-W4.3-LS5.0-FD | 1 | RST10UF25V014 | KNSCHA(科尼盛) | LCSC | C4747969 | 0.025
21 | EXPANSION HEADER (No Part Required) | U6 | HEADER MALE 2.54-1*10 | 1
22 | TYPE-C-31-M-12 | USBC1 | USB-C_SMD-TYPE-C-31-M-12_1 | 1 | TYPE-C-31-M-12 | 韩国韩荣 | LCSC | C165948 | 0.183

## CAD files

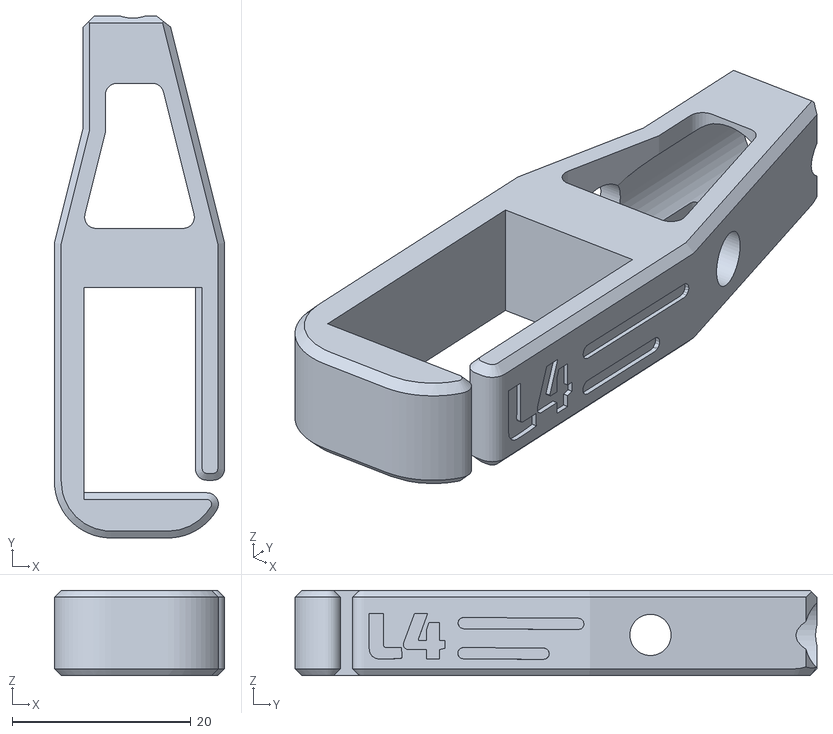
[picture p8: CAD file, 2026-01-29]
hardware/printing/stl/feet-springs/foot-joint-l4-shock-hole.stl
19.1 x 58.4 x 9.53

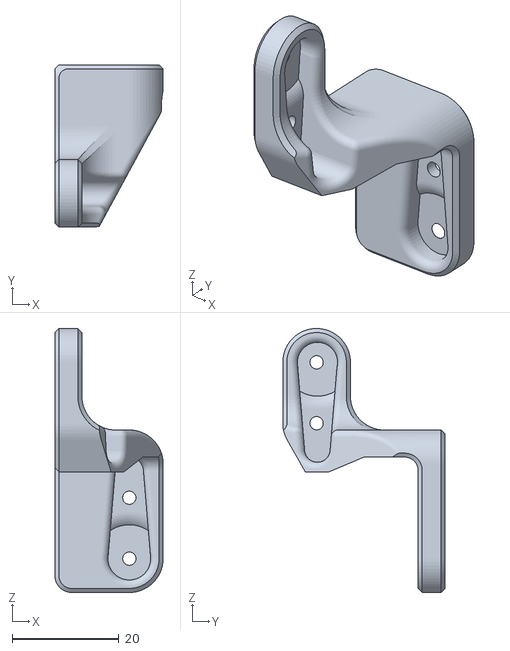
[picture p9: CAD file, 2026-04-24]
hardware/printing/stl/R1-v117.stl
20.3 x 30.5 x 49.5

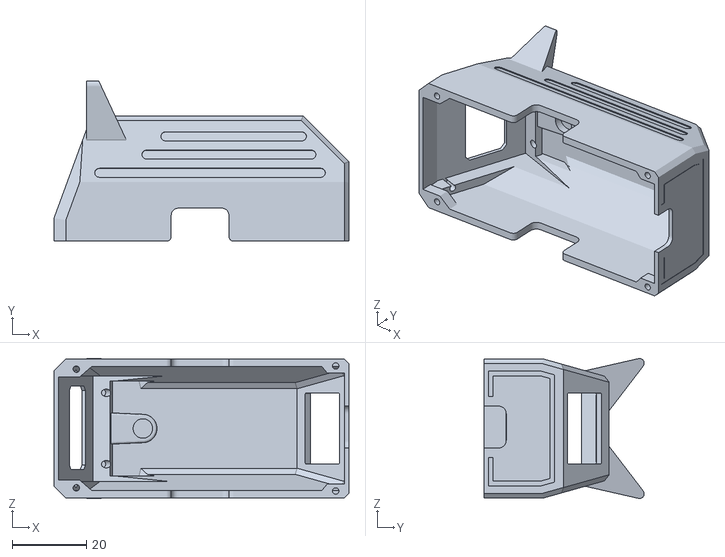
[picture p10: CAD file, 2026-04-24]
hardware/printing/stl/top-covers/Top-Cover-Cat-v100.stl
79.2 x 43.1 x 37.6

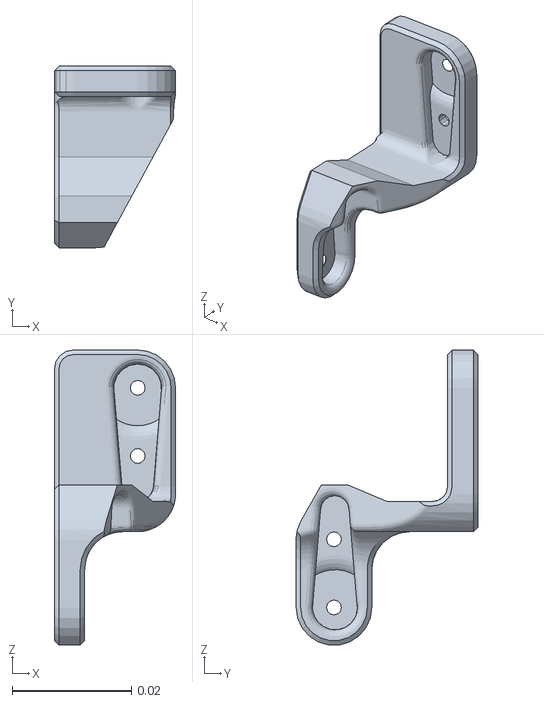
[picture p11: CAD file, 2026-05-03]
rl/imu_ideal/urdf_model/meshes/Link_L1.STL
0.0203 x 0.0305 x 0.0495

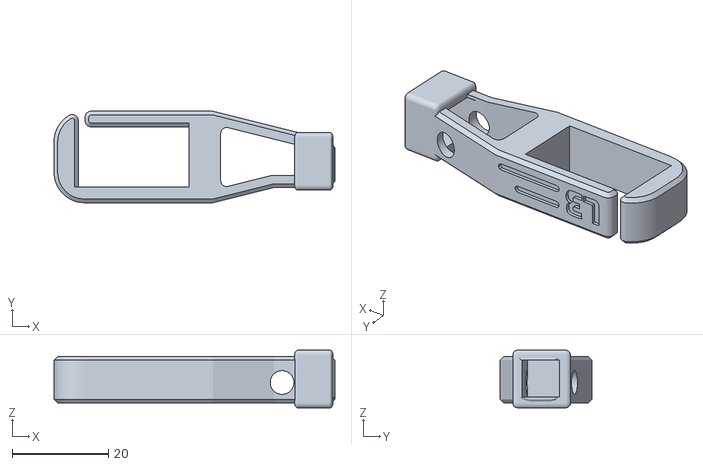
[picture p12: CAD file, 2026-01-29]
hardware/printing/stl/feet-springs/sesame leg proto shock.stl
58.4 x 19.0 x 12.0

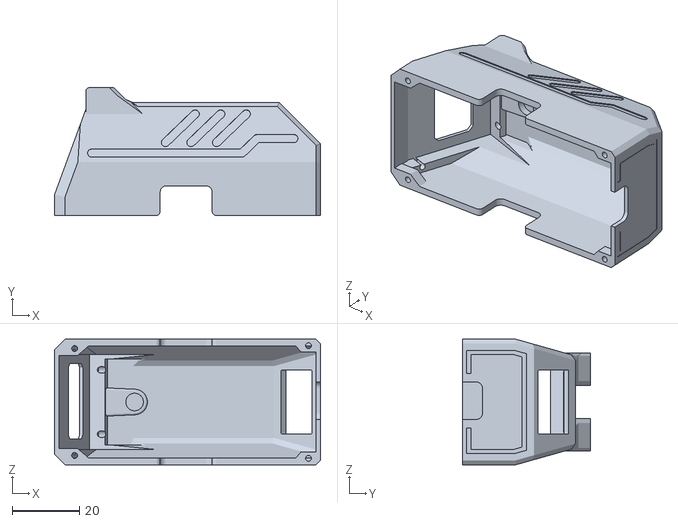
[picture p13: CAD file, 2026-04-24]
hardware/printing/stl/top-covers/Top-Cover-Enclosed-v117.stl
79.2 x 38.2 x 37.4

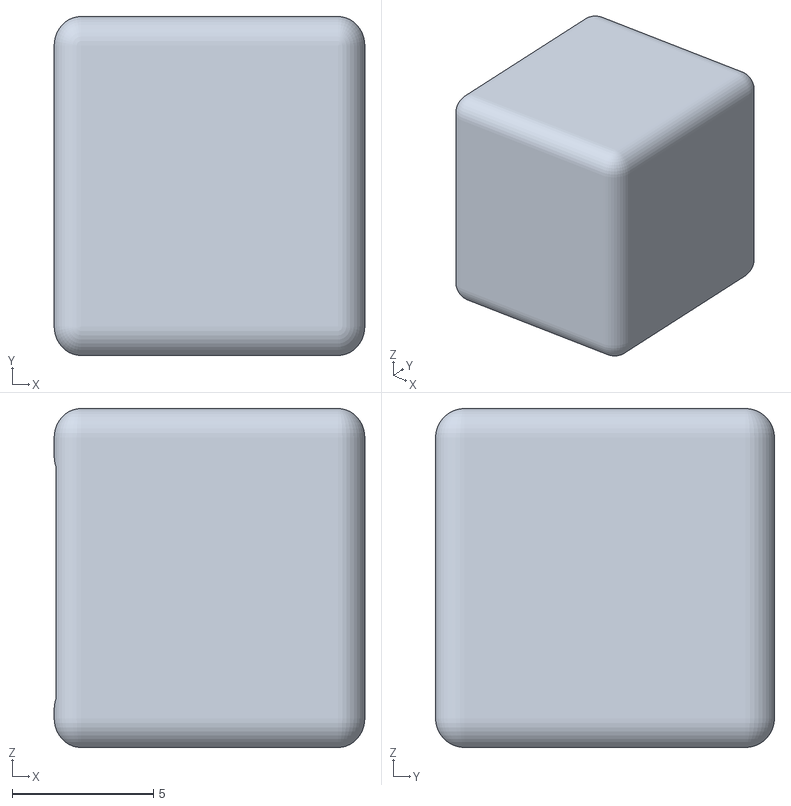
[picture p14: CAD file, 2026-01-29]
hardware/printing/stl/feet-springs/sesame leg slipper tpu.stl
11.0 x 12.0 x 12.0

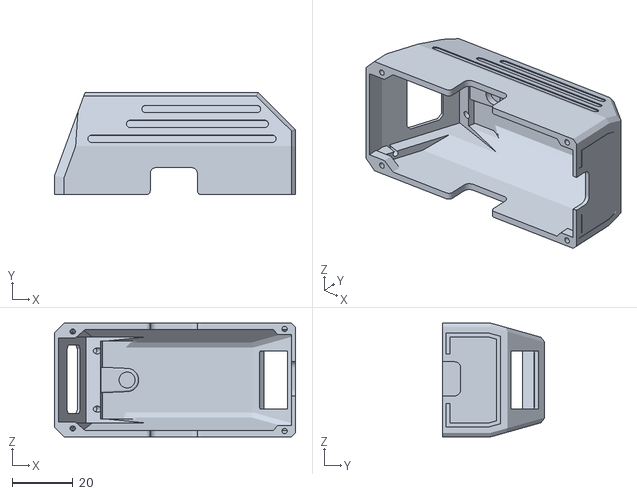
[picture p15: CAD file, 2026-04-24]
hardware/printing/stl/top-covers/Top-Cover-No-Ears-v100.stl
79.2 x 33.7 x 37.4

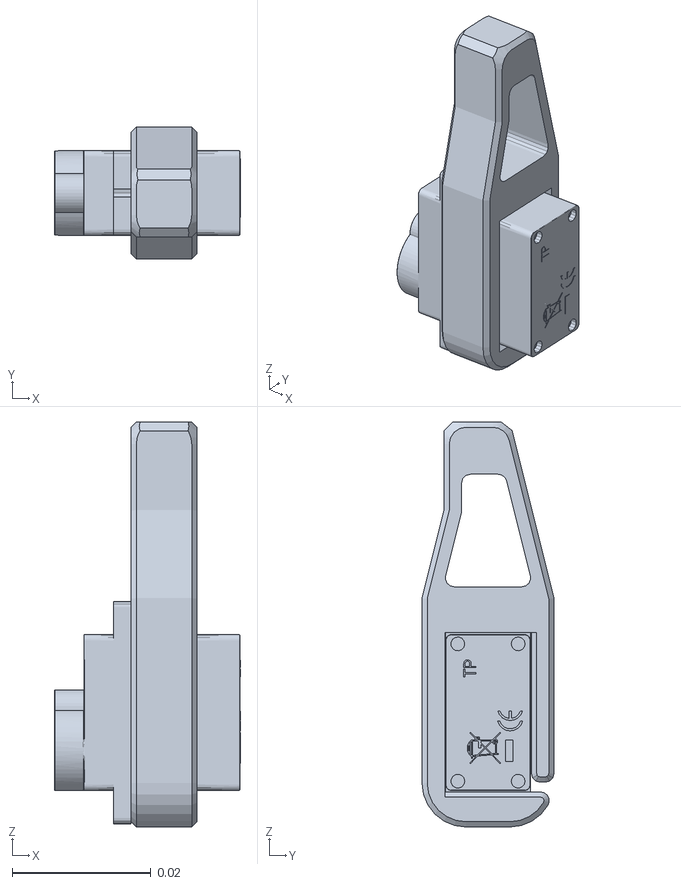
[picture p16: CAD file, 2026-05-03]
rl/imu_ideal/urdf_model/meshes/Link_R3.STL
0.0268 x 0.0191 x 0.0584

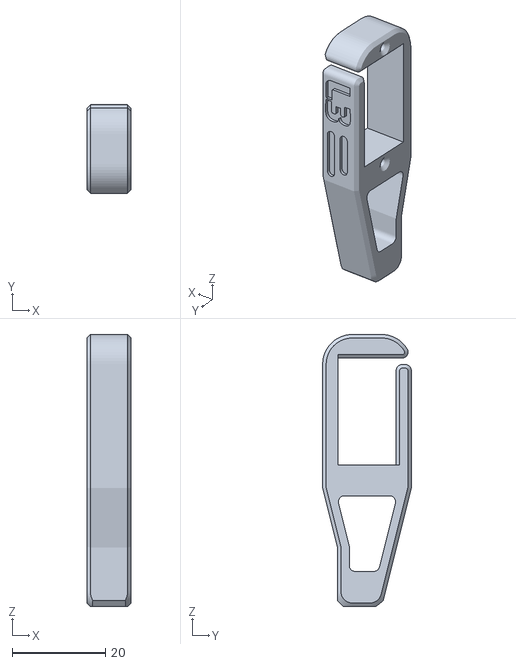
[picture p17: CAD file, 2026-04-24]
hardware/printing/stl/L3-v117.stl
9.53 x 19.0 x 58.4

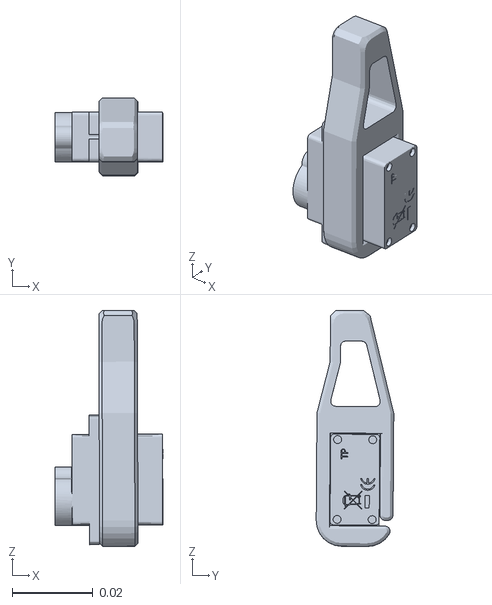
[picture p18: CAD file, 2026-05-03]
rl/imu_ideal/urdf_model/meshes/Link_L4.STL
0.0269 x 0.0192 x 0.0585

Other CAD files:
hardware/printing/stl/R2-v117.stl
rl/imu_ideal/urdf_model/meshes/Link_R1.STL
hardware/printing/stl/L1-v117.stl
rl/imu_ideal/urdf_model/meshes/Link_R4.STL
hardware/printing/stl/L4-v117.stl
rl/imu_ideal/urdf_model/meshes/Link_L2.STL
hardware/printing/stl/R4-v117.stl
hardware/printing/stl/Bottom-Cover-v117.stl
hardware/printing/stl/Internal-Frame-v117.stl
hardware/printing/stl/L2-v117.stl
hardware/printing/stl/R3-v117.stl
rl/imu_ideal/urdf_model/meshes/Link_L3.STL
rl/imu_ideal/urdf_model/meshes/Link_R2.STL
rl/imu_ideal/urdf_model/meshes/base_link.STL

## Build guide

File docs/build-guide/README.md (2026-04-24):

# Build Guide
Complete build guide for the Sesame Robot.

Use this walkthrough alongside the BOM, wiring guide, and printing notes to stay organized. The table below previews each phase, its goal, and the doc to reference if you get stuck.

| Phase | Goal | Est. Time | Key References |
| --- | --- | --- | --- |
| 1. Gather parts | Print plastics and source electronics | 1–2 sessions | [hardware/bom](../../hardware/bom/README.md), [hardware/printing](../../hardware/printing/README.md) |
| 2. Electronics & wiring | Build ~90% of the harness | 1 session | [docs/wiring-guide](../wiring-guide/README.md) |
| 3. Hardware pre-assembly | Prep joints, feet, top cover | 1 session | This guide (Phase 3) |
| 4. Hardware main assembly | Mount motors + electronics | 1–2 sessions | This guide (Phase 4) |
| 5. Calibrate & finish | Flash tester, align joints, close up | 1 session | Firmware README + remaining sections |

> [!TIP]
> Treat each phase like a milestone. Snap progress photos and mark issues before moving on so troubleshooting later is painless.

<p align="center">
  <a href="https://www.youtube.com/watch?v=NIgoQVQF_Ng">
    tutorial-button
  </a>
</p>

## Phase 1: Gathering all the parts.

**Goal:** Print the full shell set and collect every electronic, connector, and fastener before any soldering starts.

**You’ll need:**
- [hardware/bom](../../hardware/bom/README.md) for electronics, power gear, and Amazon search links.
- [hardware/printing](../../hardware/printing/README.md) for STL names, orientations, and support notes.

There are 11 printed parts (internal frame, top/bottom covers, joints R1–R4/L1–L4) plus 6–8 main electronic components depending on the wiring approach.

Here's what a complete set looks like:

all-hardware

**Phase 1 checklist**
- [ ] All plastic parts printed, and cleaned up.
- [ ] MG90 servos tested quickly on a servo tester or Arduino to catch DOA units.
- [ ] Power plan decided (USB-C PD vs. battery + buck) and matching connectors sourced (2× 10440 Li-ion cells in a 2× AAA holder fit the stock battery cavity).
- [ ] Consumables stocked: solder, flux, heat-shrink, zip ties, M2 hardware.

## Phase 2: Electronics and Wiring

**Goal:** Build 90% of the harness on the bench so the frame install is quick.

1. Open the [wiring guide](../wiring-guide/README.md) and pick the section that matches your build (S2 Mini hand-wired, Distro Board V2, or Distro Board V1 legacy).
2. Lay out every connector in the order shown on the wiring diagram before soldering; this keeps the data lines from getting crossed.
3. Tin and solder the rails/buck converter first, then route signal wires. Leave generous length for the motors that terminate near the hips.
4. This is optional but you can also label each servo lead (S0–S7) using tape flags as soon as it is soldered. Future you will thank you.

> [!WARNING]
> Stop before permanently wiring the power switch or OLED. Those final joints happen after the electronics are seated in the frame so you can dial the cable length exactly.

**Phase 2 checklist**
- [ ] Harness built per your wiring diagram with all joints strain-relieved.
- [ ] Buck converter trimmed to 5.1 V output and shrink-wrapped.
- [ ] Servo leads labeled and loosely bundled by destination.
- [ ] Power switch and OLED leads pre-cut but still un-soldered.

## Phase 3: Hardware Pre-Assembly

### Hip Joints

**Goal:** Pre-load the four hip joints (R1, R2, L1, L2) with one-sided servo horns so installation is tool-free later.

1. Lay out the four hip joint parts. Find the one-sided servo horns from the servo motor bags (ignore the included extra screws).
2. Notice the servo horn has a taller side and a shorter side. Press the shorter side into the hip joint. There should be just enough clearance to press this piece in flush.
3. While holding the horn flat, drive an M2 × 5 mm self-threading screw (the ones with a larger gap between thread spikes) through the second hole in the horn and into the plastic until secure.

install-horn

> [!TIP]
> Do not over-tighten self-threading screws. Since the threads are plastic, over-tightening will permanently damage the hole.

Repeat for all four hip joints:

hip-joints

> [!IMPORTANT]
> Do **not** mount these joints on the servos yet. Calibration requires every motor shaft to spin freely.

dont-mount

### Leg Joints

Slide each leg shell over its dedicated motor before the frame install. Use the built-in gap to route wires without pinching them.

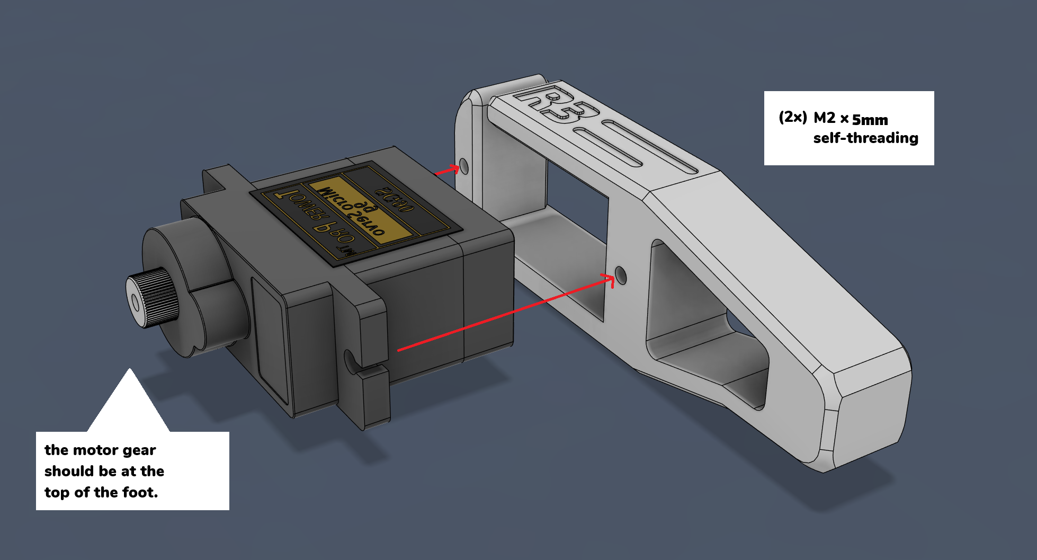
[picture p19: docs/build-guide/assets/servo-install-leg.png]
servo-install-leg


- Feed the motor wires through the side slot.
- Push the motor into the side of the leg piece that has holes in it. Make sure the motor shaft is at the very top.
- Confirm the motor sits flush and use self-threading screws to permanently affix the motors into the leg pieces.

Repeat for the remaining legs.

leg-joints

### Top Cover & Soldering

The next step is loading the OLED and power switch into the top cover. At this stage, we also do the minimal soldering required for the build.

1. **Power Switch:** Press the battery switch firmly into the back slot of the top cover. DO NOT connect the wires yet.

insert-rocker-switch

2. **OLED Display:** Apply a small amount of solder to the pin headers on the display (tinning). Using the pre-crimped JST connector wires, match the wires to their respective marks on the display and solder them. 

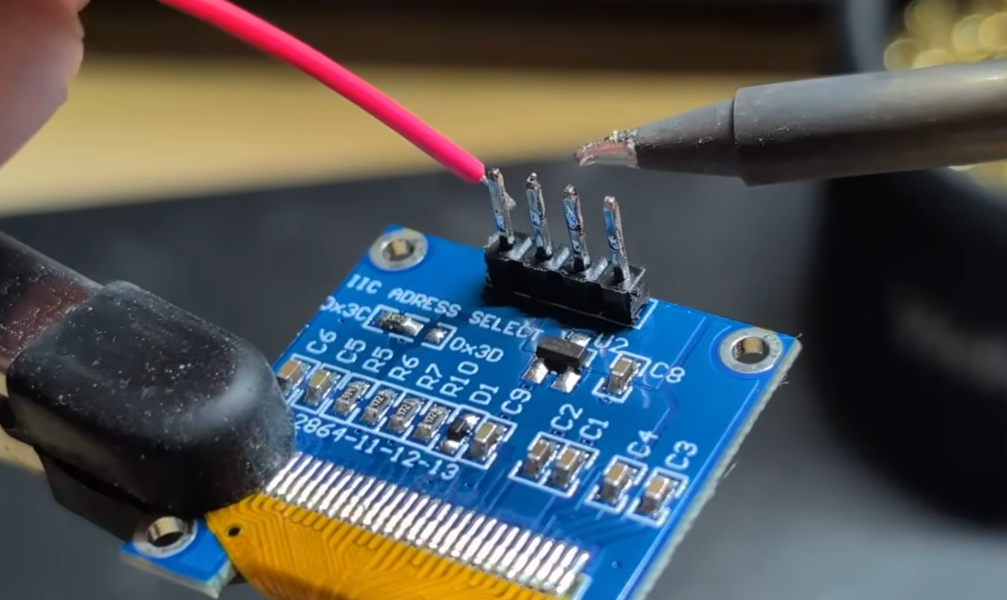
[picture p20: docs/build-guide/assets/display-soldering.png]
display-soldering


3. **Battery Connectors (Main Board):** Remove sheathing on the ends of the battery connector wires, tin them, and solder them to the battery pads on the main board in an L-shape pointing upwards. Make sure they do not go over the edge of the board, or the top cover won't fit.

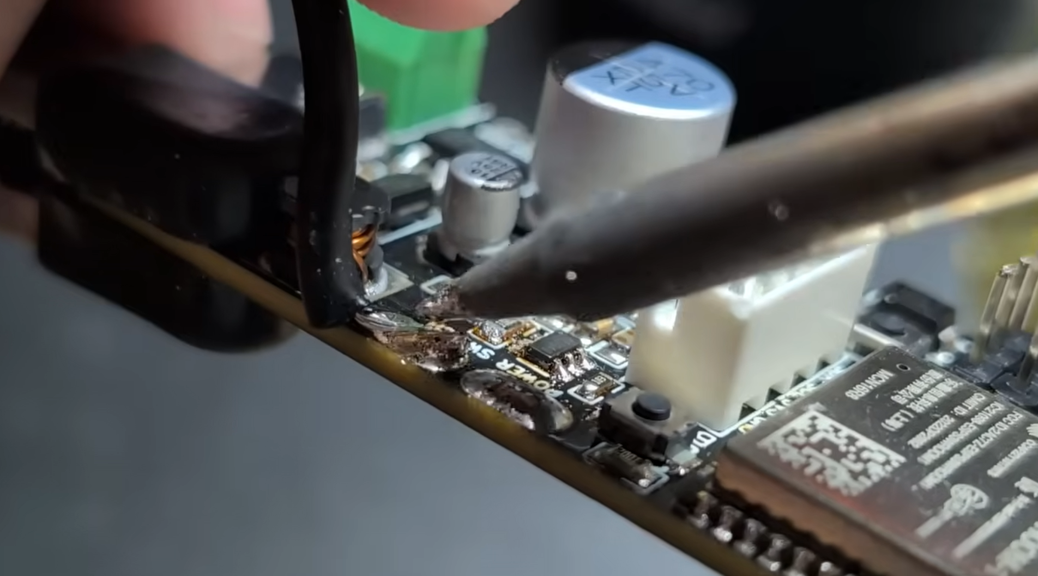
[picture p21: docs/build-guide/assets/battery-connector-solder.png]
battery-connector-solder


4. **Install Display:** Push the wired OLED display gently into its slot inside the top cover. Insert self-threading screws into the small screw holes beside the display to clamp it permanently in place.

securing-display

**Phase 3 checklist**
- [ ] Hip joints pre-loaded with servo horns, not yet attached to motors.
- [ ] Leg pieces installed on every motor.
- [ ] Power switch and OLED display installed in the top cover.
- [ ] Battery connectors soldered to the main board.

## Phase 4: Hardware Main Assembly

**Goal:** Seat the frame motors, route wiring, and secure the electronics stack so the robot is ready for calibration.

1. **Battery Holder:** Insert the battery holder into the back of the internal frame piece. Route the red and black wires up the slot.
2. **Motor Installation:** While holding the battery wires in place, insert the four remaining side motors. The motor shaft should be facing towards the outside of the internal frame.
  - Insert motors at an angle and press them the rest of the way. Make sure not to pinch any wires at the bottom.
3. **Secure Motors:** Use self-threading screws to permanently affix all four side motors to the frame.

insert-motors

rotate-motor

Make sure the motor shafts are closest to the outer edge of the frame. 

complete-motors

## Installing the Main Electronics

Before dropping hardware in, trim or bundle any stray wires so nothing can flop into the servo gears and double-check that every connection exits upward.

1. Pre-route any long wires upward so they naturally hug the future top cover.
2. Lower the electronics harness into the cavity while keeping the USB port toward the rear.
3. **S2 Mini build:** Screw the controller (and optional protoboard) directly into the frame using the provided mounting holes. If you built a small protoboard backplane, use the spare holes in the internal frame to secure it so the servo plugs are easy to reach later.

s2-secure-electronics

4. **Distro Board V1 build (Legacy):** Install four M2.5 × 5 mm male-female standoffs to raise the Sesame Distro Board V1 so it clears the ESP32 DevKit. Then secure the assembly using the top screws.

secure-distro-board

5. **Distro Board V2 build (Build Kits):** Mount by gently bringing cables towards the center nicely so that the main board can sit properly. Attach the main board to the internal frame. It has two mounting holes in the corner that you attach using self-threading screws.

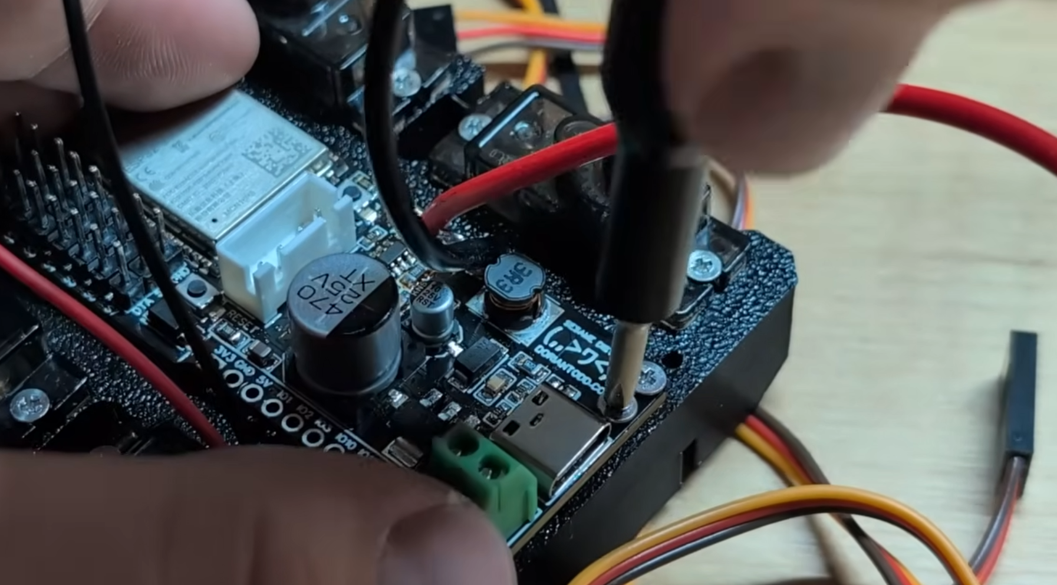
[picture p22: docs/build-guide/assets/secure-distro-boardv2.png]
secure-distro-boardv2


> [!TIP]
> Notch = front. USB port = back. Use these two cues any time the orientation feels ambiguous.

## Calibrating & Running the Testing Firmware

**Goal:** Teach the controller where each motor sits so the walking poses land correctly.

> [!CAUTION]
> Never run calibration with joints attached. A misaligned horn can stall or strip a servo instantly. All motor shafts should be free spinning at this point.

**For S2 Mini and Distro Board V1 (Legacy) Builds:**
1. Inspect the harness to ensure no bare conductors can short during testing. Add heat-shrink or tape where needed.
2. Connect a reliable USB-C cable and flash `sesame-motor-tester.ino` from the [debugging-firmware](../../firmware/debugging-firmware/) folder using Arduino IDE. If you have never flashed an ESP32 before, pause here and follow a quick tutorial so you are comfortable resetting/entering boot mode.
3. Open the serial monitor. You should see the tester menu.
4. Command all motors to 90°. Starting from Motor 0, plug its connector into the appropriate header. The servo should immediately whirr into the 90° position. Repeat for Motors 1–7. Skip to Step 4 below.

**For Distro Board V2 (Build Kits):**
If you are using the V2 Board from a Build Kit, it comes **pre-flashed** with the Sesame firmware! There is no need to plug into a computer and use Arduino IDE to flash firmware. 

1. **Power Up:** Plug the board into a strong USB power supply (fast chargers for phones or laptop chargers work great). Note: If you are using the V2 Distro board, it currently has instabilities with the battery system and won't work on batteries, you must plug via USB-C (A V3 Distro board fix will be sent). 
2. **Connect to Portal:** Check the Wi-Fi networks on your phone or computer. The Sesame board will create an access point. Connect to it to open the controller portal. (If on desktop and the portal doesn't show, go to `sesame-root.local` in your browser. Mobile is recommended.)
3. **Initialize PWM:** Tap the "Standby" button in the portal to initialize the PWM channels. The moment you plug a motor in, it will go to its correct active position.

**General instructions continuing:**

4. **Refer to Diagram:** Use the diagram below to associate motor numbers with their physical position. Ensure the frames are roughly oriented correctly.

angle-guide

5. **Plug Motors In:** Starting with Motor 0, plug the connector into the corresponding board header. 
   - **Crucial:** Ensure the brown wire aligns with the ground rail! Upon plugging it in, you should hear it whir into life and hold position. 
   - Repeat for all 8 motors. 

> [!TIP]
> 99% of the time, if your motor is moving in the wrong direction, crashing, or being sporadic, the motor is plugged into the wrong slot. Check your wiring!

## Attaching Hip & Leg Joints

Now we attach the joints while the motors are turned on and holding their "Stand" position.

1. **Hip Joints:** Select the matching hip joint for your motor. While in "Stand" mode, push the hip joint onto the motor shaft at a 45-degree angle. 
2. **Test Angles:** Tap "Rest" in the portal. The hip joint should move perfectly parallel to the body. Tap "Stand" again, and it should go back to 45°. Alternate this to ensure it's placed correctly.
3. **Fasten Hip:** If it looks good, fasten the hip joint to the motor using an M2.5 machine screw through the main hole into the motor shaft. Gently tighten (don't over-torque against the motor as this may cause a brownout).
4. **Legs:** Repeat the same process with the leg joints. Check against "Rest" and "Stand", ensure nothing collides, and then affix using screws.

reference-configuration

## Final Wiring and Top Cover

Now to clean up the robot and secure everything. 

1. **Battery Connections:** Insert the battery wires into the screw terminal on the board and use a flathead screwdriver to tighten them securely.
2. **Wire Routing:** Flip the robot over. There are channels for all the wires on the underside. Securely press all of the wires into these channels.
3. **Bundling:** Separate the wires gently into two groups (left and right). Wrap a zip tie around each bundle, fold it once, and tighten the zip tie to create a tight bundle. This helps the top cover fit seamlessly. 

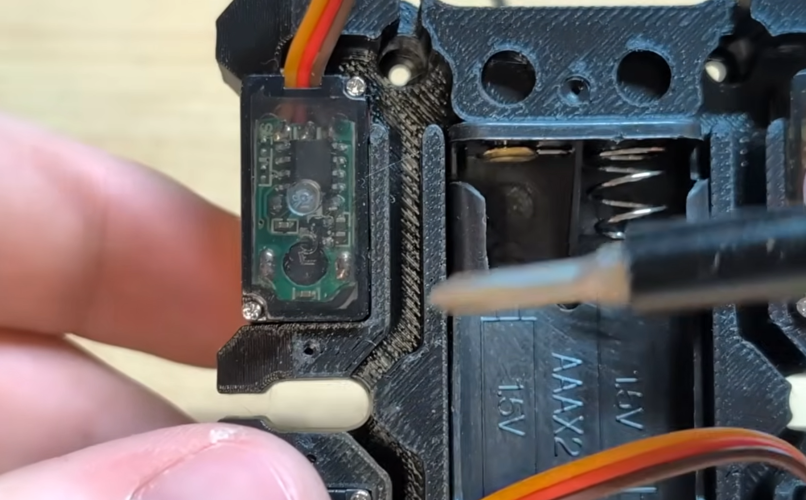
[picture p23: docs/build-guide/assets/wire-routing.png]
wire-routing


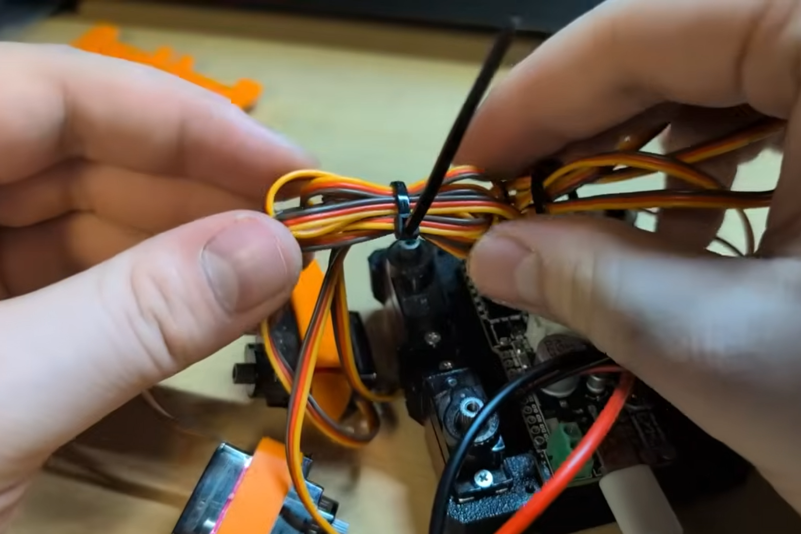
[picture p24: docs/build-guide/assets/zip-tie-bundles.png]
zip-tie-bundles


4. **Testing the Switch:** Make sure the batteries are charged and insert them. Flip the switch and check if the Wi-Fi network appears or if the display lights up. If things aren't working, double-check connections.

> [!NOTE]
> **V2 Board Owners:** If you are using the V2 Distro board from a kit, there are instabilities with the battery system that prevent reliable battery usage. You must run your Sesame via USB-C (fast charger / laptop charger) for now. A free V3 Distro board will be provided to pre-order kit buyers!

5. **Top Cover:** Gently pack all the bundles in and slowly press the top cover down onto the electronic components. Be very gentle to avoid shorting or disconnecting anything.
6. **Securing Top Cover:** Hold the whole robot together and insert the M2 self-threading screws into the bottom of the frame where they thread securely into the mounting holes for the top cover.

secure-top-cover

## Bottom Cover & Final Checks

insert-battery

1. Set the bottom cover in place, checking that no wires are trapped. Use the remaining two self-threading screws into the bottom to secure it. 

screw-on-bottom-cover

2. You can apply the included sticky pads to the feet if you like!

**Phase 4 checklist**
- [ ] Motors mounted and screwed in on hip and leg joints.
- [ ] Harness routed into channels, zip-tied without pinch points.
- [ ] Top and bottom covers installed.

> [!TIP]
> A common issue on battery power (if you upgrade) is that your Sesame robot will crash on movement. Setting the motor current delay higher in the settings may help, but upgrading to a Lithium Polymer (LiPo) cell often solves it for advanced users! 

Great job! The hardware is complete.

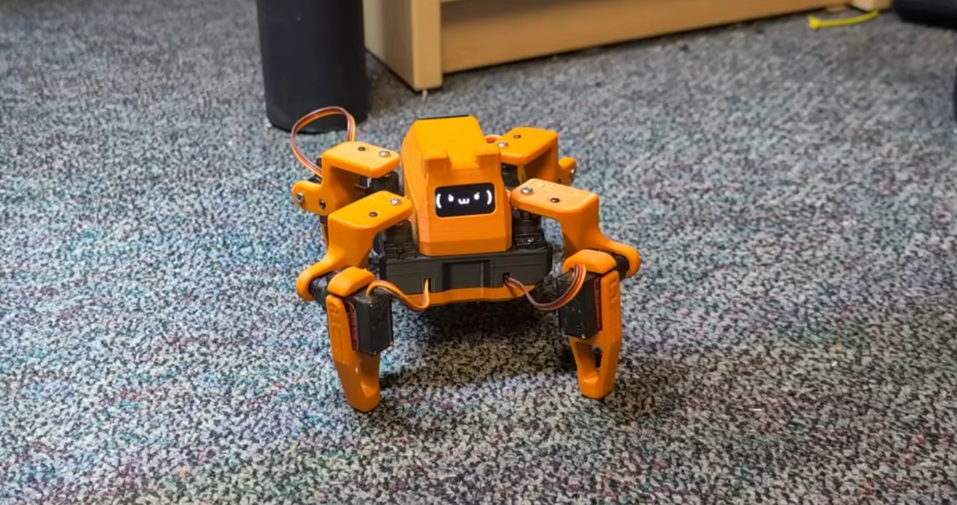
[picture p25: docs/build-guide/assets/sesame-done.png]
sesame-done


## Final Checks and Flashing the Firmware

Now we just need to do a few checks to make sure everything is working and we can flash the firmware onto the microcontroller.

**Sanity checks**
1. Toggle the power switch (if you installed a battery) and confirm it fully disconnects the pack.
2. Confirm the USB-C port is accessible for future firmware updates.
3. Inspect the OLED wiring one last time to ensure SDA/SCL aren’t swapped.

**Flash production firmware (For DIY / S2 Mini / Distro V1)**
If you are using the V2 Build kit board, you can skip this step! It is pre-flashed.
1. Choose the code variant from the firmware folder. Customize pin definitions if you're using a different ESP32.
2. Use Arduino IDE to flash the full firmware bundle (motors + faces). Detailed notes live in [firmware/README.md](../../firmware/README.md).
3. Connect to Sesame’s Wi-Fi AP, load the control page, and trigger a pose to verify everything moves as expected.

That’s it. You’ve built Sesame! From here you can design new poses in [Sesame Studio](../../software/sesame-studio/README.md) or tweak the hardware per [hardware/README.md](../../hardware/README.md), or whatever you want!

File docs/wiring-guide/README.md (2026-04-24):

# Wiring Guide

Complete wiring guides for the Sesame Robot.

---

## Choosing a Wiring Approach

The project supports multiple wiring strategies that suit different build constraints:

- **Lolin S2 Mini / hand wiring (RECOMMENDED FOR DIY BUILDS):** Uses a Lolin S2 Mini, loose headers, and point-to-point wiring. It is the lowest-cost option, easy to source, supports USB-C PD for tethered power, but demands patience to keep the harness tidy and leaves less room for mistakes. **Critical: Use 30AWG wire for data lines and 22AWG for power—larger gauge wire will make assembly nearly impossible.**
- **Sesame Distro Board V2 (INCLUDED IN BUILD KITS):** The latest custom PCB with SMD components, supports both USB-C PD and battery power. Pre-flashed and included with all Sesame Build Kits. Advanced to hand-solder; professional assembly recommended if ordering separately.
- **Sesame Distro Board V1 / ESP32-DevKitC-32E (LEGACY):** Uses the custom Distro Board V1 PCB stacked on an ESP32-DevKitC-32E. Now phased out but still supported. V1 has known limitations and cannot run on tethered USB-C power (battery + buck converter required).

Pick the approach that matches your component availability and comfort with managing wire bundles; the remainder of this guide dives into both workflows.

## How to wire the Lolin S2 Mini / Hand Wiring

The Lolin S2 Mini method is a traditional protoboard build. Consult the S2 Mini wiring diagram below while reading this section; it captures every motor, sensor, OLED, and button lead even if the photos only show a subset of the connections. Expect a high connection count, so plan wire lengths and colors before soldering to avoid confusion later.

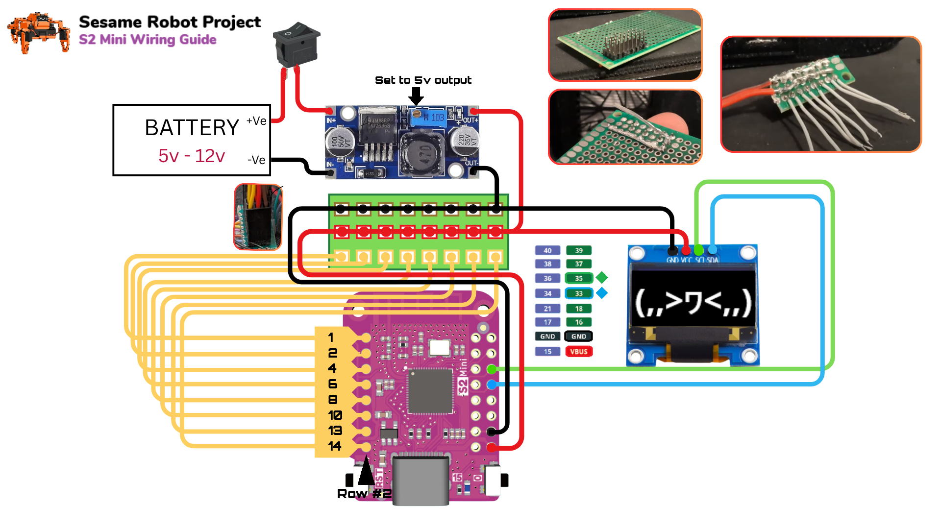
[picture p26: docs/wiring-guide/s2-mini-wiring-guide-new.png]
S2 Mini wiring diagram


*Credit to @captianeverypowersr on Discord for the new S2 mini guide.*

### Prep

1. **Secure and tin** all of the connections on the board before starting
2. To connect all the 3-pin headers together and to the board, first attach them to a small section of protoboard

proto-headers

### Building Power and Ground Rails

1. Solder one wire to one end of the pins, then guide it along and remove the insulation
2. Solder this exposed wire to every middle pin (this creates the **5V rail**)
3. Do the same for the ground lane (this creates the **ground rail**)

proto-power-rails

### Data Lines

You can now cut eight equal-length wires for data connections.

**Wire Recommendations:**

- **Data lines:** 30AWG silicone wire
- **Power and ground:** 22AWG silicone wire
- **Important:** Things will get super cluttered if you use large gauge wire

proto-data-lines

Alongside the eight motor data leads, the diagram also calls out the OLED connections that branch from the microcontroller.

### Packing Electronics

When packing electronics into the frame, it's difficult with the hand wiring setup because there are a lot of stray wires. My advice is to work slowly and methodically:

1. Group wires with similar destinations
2. Use zip ties and heat shrink tubing to make them as compact as possible
3. Consider connecting the power switch after finishing most other wiring, since it's attached to the top cover

wire-managment

### Safety and Testing

> [!CAUTION]
> Do not solder and de-solder connections with power connected!

**Before powering on:**

- Double check your power and ground lines before turning the robot on
- Make sure to cover any exposed wires as they can touch the pin headers and fry the ESP32 (especially when cramming the cover on)

> [!TIP]
> To make fishing out the wires for the OLED display easier, you can temporarily twist them together into a group and then guide them through the opening in the top cover.

---

## How to wire the Sesame Distro Board V1 / ESP32-DevKitC-32E

### Overview

> [!CAUTION]
> UPDATE 1/20/26: Upon further testing, the Sesame distro board V1 will work, but it has a few issues that make it a little harder to assemble and will not run on teathered power (eg. USB C). Until V2 is released, I recommend using the S2 Mini / Hand Wiring approach. If you ordered a distro board V1, it will still be supported with wiring guides and firmware for the foreseeable future <3.

This option provides a cleaner, more organized wiring solution.
Consult the distro-board wiring diagram below for exact connection locations.

> [!IMPORTANT]
> **ESP32 Pin Header Requirement:** The distro board V1 stacks on top of the ESP32-DevKitC-32E, so you need an ESP32 board **without pre-soldered pin headers**. If your board came with headers already soldered on the top, you will need to desolder all of the headers and flip them to the bottom side of the ESP32 board so the distro board can mount on top.

distro-board wiring diagram

### Component Installation

**Optional components** (you can solder directly to pads instead):

- 4-pin JST connector
- 2-pin screw terminal

**Pin header installation tip:** If you're having difficulties keeping the pin headers in place to solder, try placing them in a protoboard first, then transferring them over.

### Buck Converter Setup

A buck converter takes any voltage (5V-12V) and drops it to a stable 5V for the motors and ESP32.

**If using a battery:**

1. Make sure to solder the buck converter enable pads
2. The buck converter is **required** for battery operation
3. 2× 10440 Li-ion cells in a 2× AAA holder (2S, ~7.4 V nominal) work well with the buck and fit the chassis battery slot

**Alternative power options:**

- If you're using a benchtop supply or have another regulated 5V source
- You can override the buck converter and take voltage directly from the screw terminal by soldering the override pads

### Battery Connection

> [!CAUTION]
> If your battery has an XT30 or JST RCY connector, don't cut it off and wire the battery directly to the distro board! This is unsafe and means you can't charge your battery anymore.

**Proper method:**

1. Get a female XT30 or JST RCY connector (matching your battery)
2. Wire it to two wires that lead to the power terminal
3. This allows you to safely connect and disconnect the battery

**Note on 2× AAA holders with 10440 Li-ion cells:**

- Treat this as a 2S Li-ion pack; wire the holder leads through the switch and buck converter.
- **Always remove the 10440 cells from the holder and recharge them separately using a proper Li-ion charger.** Most AAA holders do not support safe Li-ion charging and attempting to charge in-holder can be dangerous.

### Sourcing the Distro Board

The Sesame Distro Board V1 is a custom PCB designed specifically for this project. It mounts on top of a ESP32-DevKitC-32E.

More information is avalible in the [PCB](../../hardware/pcb/README.md) section of the documentation.

---

## General Wiring Tips

- Work slowly and methodically
- Test connections before applying power
- Keep wire runs as short and neat as possible
- Label wires if helpful for troubleshooting
- Take photos during assembly for reference

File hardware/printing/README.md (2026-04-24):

# 3D Printing Guide

Sesame is designed to be printed in **PLA**. Most parts print without supports, but the top cover needs supports in targeted areas. Below is a quick reference for each component:

Note: There are 3 different top cover styles currently available. **Enclosed v91 is recommended** as it's the most modern design with magnetic hat mounts, covered display wires, and multicolor detail support. See [Top Covers](stl/top-covers/) for details on all styles.

## Recommended Settings
* **Material:** PLA / PLA+
* **Infill:** 8-10%
* **Wall Loops:** 2
* **Infill Pattern:** Honeycomb

## 3D Printed Components Support Guide

| Component | Supports Required | STL Link |
|---|---|---|
| Joint R1 | No | [R1-v117.stl](stl/R1-v117.stl) |
| Joint R2 | No | [R2-v117.stl](stl/R2-v117.stl) |
| Joint R3 | No | [R3-v117.stl](stl/R3-v117.stl) |
| Joint R4 | No | [R4-v117.stl](stl/R4-v117.stl) |
| Joint L1 | No | [L1-v117.stl](stl/L1-v117.stl) |
| Joint L2 | No | [L2-v117.stl](stl/L2-v117.stl) |
| Joint L3 | No | [L3-v117.stl](stl/L3-v117.stl) |
| Joint L4 | No | [L4-v117.stl](stl/L4-v117.stl) |
| Internal Frame  | No | [Internal-Frame-v117.stl](stl/Internal-Frame-v117.stl) |
| Bottom Cover | No | [Bottom-Cover-v117.stl](stl/Bottom-Cover-v117.stl) |
| Top Cover | Yes | [Top Covers](stl/top-covers/) |

### Top Cover Settings (Original Style)

Brim: Outer brim only
Support type: Normal (Manual)

Manual support locations:

topcover-supports2

This is what the part should look like sliced:

sliced-topcover

### Recommended Print Orientation for Joints:

Using the auto orientate tool will place these the correct way. 

sliced-topcover

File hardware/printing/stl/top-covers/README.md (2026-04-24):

# Top Cover Styles

## Enclosed v100
Current modern version of sesame top cover, includes 5mm x 2mm magnet slots for hats! Front display wires are covered, supports multicolor details.

## Cat v100
Modern Version of the enclosed top cover with cat ears instead of stubby ears! Updated with all current features with magnet support for hats, and multicolor details.

## No Ears v100
Template for designing your own ears for Sesame. The areas right next to where the ears ussually go is a little thin so this version is only really meant for desiging ears onto. (Includes all previously mentioned features)

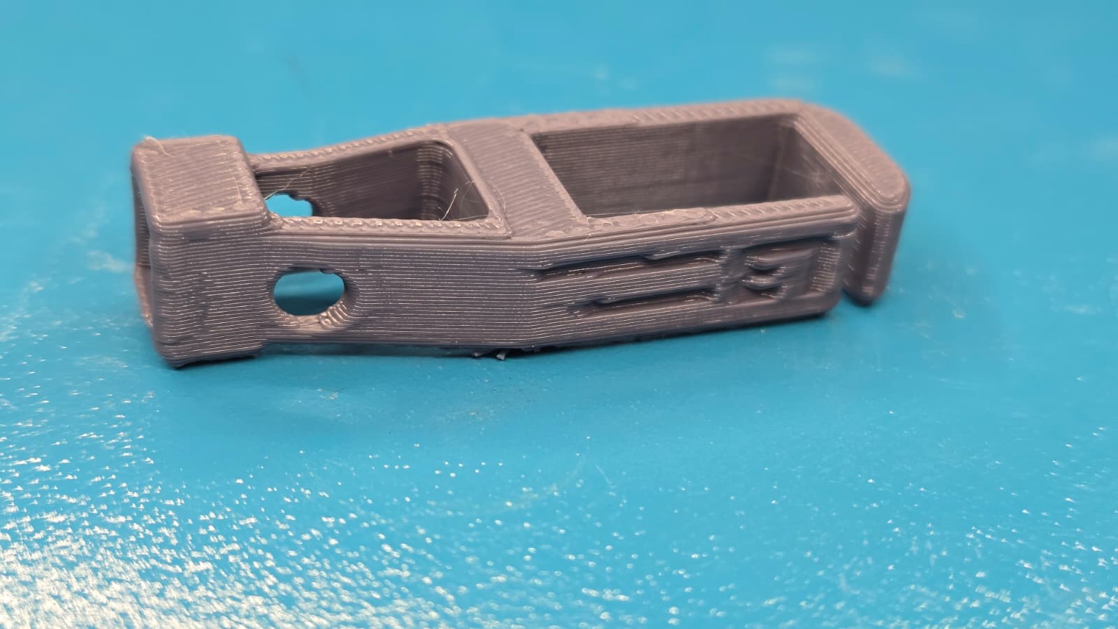
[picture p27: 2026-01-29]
hardware/printing/assets/feet-joint-l3-nylon-side.jpeg

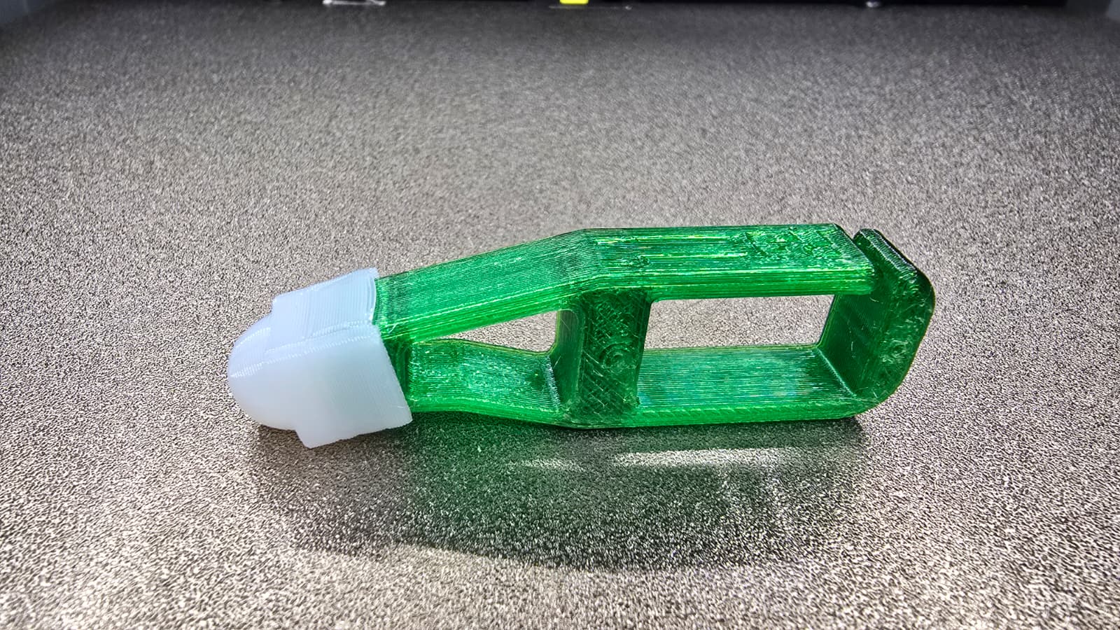
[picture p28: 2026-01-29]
hardware/printing/assets/feet-tip-toe-tpu-4.jpg

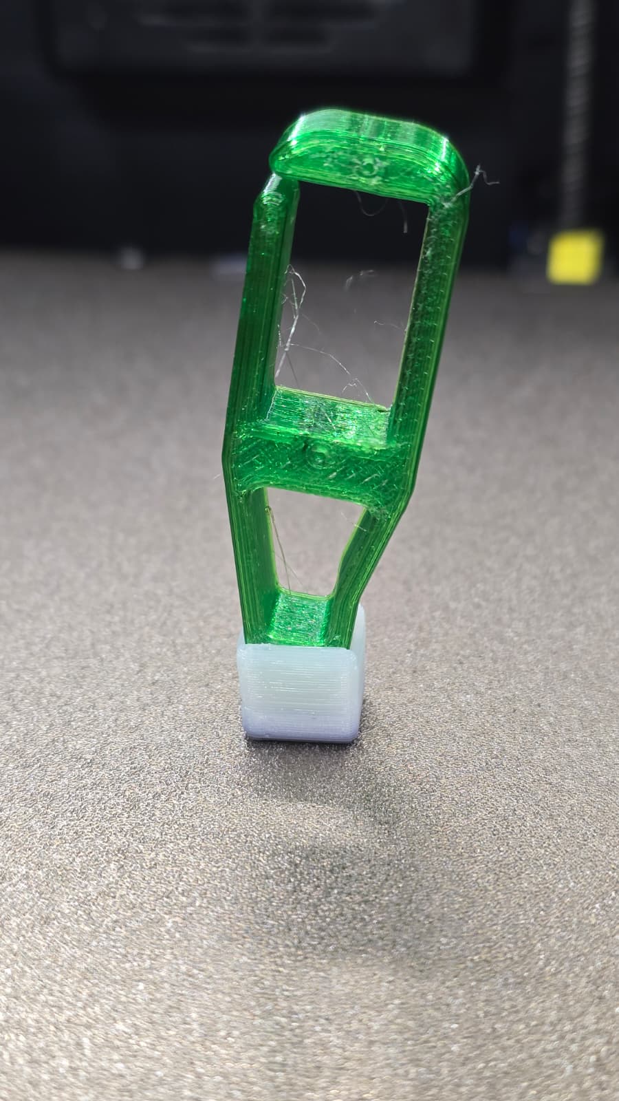
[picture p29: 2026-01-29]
hardware/printing/assets/feet-joint-l3-side-tpu.jpeg

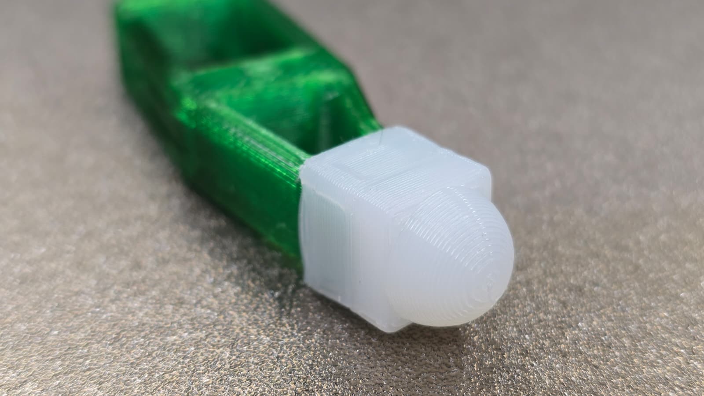
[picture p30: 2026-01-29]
hardware/printing/assets/feet-tip-toe-tpu-2.jpg

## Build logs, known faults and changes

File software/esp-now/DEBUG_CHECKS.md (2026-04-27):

# ESP-NOW Quick Debug Checks

Use this checklist when the robot or controller isn't responding as expected.

---

## Controller Boot Debug

When the ESP32-C3 controller boots, it prints:

```
=== ESP32-C3 Sesame Controller ===
Protocol version: 1
Controller MAC: AA:BB:CC:DD:EE:FF
ESP-NOW Channel: 1
Robot MAC: DC:54:75:C8:43:00
Robot peer registered
```

**Expected:**
- Controller MAC is present ✓
- Robot MAC is configured ✓
- "Robot peer registered" appears ✓

**If Robot MAC shows all `FF:FF:FF:FF:FF:FF`:**
- Run `SET_ROBOT_MAC <mac>` with the robot's MAC address
- The robot MAC is printed by the robot at boot (see Robot Boot Debug)

---

## Robot Boot Debug

When the robot boots, it prints:

```
=== Sesame Robot (ESP-NOW) ===
MAC Address: DC:54:75:C8:43:00
ESP-NOW Channel: 1
Copy this MAC address to the ESP32-C3 Controller!
...
Controller peer registered: AA:BB:CC:DD:EE:FF
```

**Expected:**
- Robot MAC printed at top ✓
- "Controller peer registered" appears **after the controller first contacts it** ✓

**If "Controller MAC not set":**
- Expected on first boot — robot will auto-register when controller sends first message
- If it never registers, check that the controller MAC is correct

---

## Basic Connectivity Test

**On controller:**
```
PING
```
**Expected response:**
```
PONG rtt=1.23ms
```

**If timeout/error:**
1. Verify both devices show same ESP-NOW channel
2. Verify controller knows robot MAC (`MAC` command shows controller's own MAC, `SET_ROBOT_MAC` was used)
3. Power cycle both boards
4. Bring boards within 1m of each other

---

## Command round-trip Test

**On controller:**
```
CMD wave
```
**Expected robot serial output:**
```
[ESP-NOW] Motion: wave
```
**Expected controller response:**
```
OK
```

Then the robot plays the wave animation.

**If no response on robot:**
- Controller logs `OK SENT` but robot doesn't print → ESP-NOW packet not arriving
  - Check MAC addresses
  - Check channel match
  - Check distance/interference
- Controller logs error → send failure
- No controller response at all → robot never ACKed

---

## Status Check

**On controller:**
```
STATUS
```
**Expected response:**
```
STATUS cmd=wave face=wave
```

Useful to verify robot's internal state.

---

## ESP-NOW Channel Mismatch

**Symptoms:**
- PING times out
- Commands never arrive
- No "Robot peer registered" on robot

**Fix:**
1. On controller: `CHANNEL 1` (or 6, 11 — pick one)
2. On robot: Change `ESPNOW_CHANNEL` in `espnow-protocol.h` to same value
3. Reflash robot
4. Restart controller

**Tip:** Use the `WiFi_Channel_Scanner` sketch to see which channels are crowded.

---

## MAC Address Mismatch

**Symptom:** PING sends but never gets PONG. Controller prints "ERR Response timeout".

**Debug:**
1. Robot boot log prints its MAC — copy it exactly
2. On controller: `SET_ROBOT_MAC <that_mac>`
3. Wait 2 seconds, then `PING`

**Controller MAC** — just informational; robot auto-accepts first sender. If you want to lock it down, you would hardcode it in the robot firmware (currently not required).

---

## Controller keeps losing peer registration

ESP-NOW peers can be deleted by WiFi events or power loss.

**Fix:** The controller re-adds the peer on every boot (in `setup()`). If the robot changes MAC or the pairing is lost:
1. `SET_ROBOT_MAC <current_robot_mac>` on controller
2. Restart both devices

---

## Robot serial debug commands

While ESP-NOW is running, you can still connect a serial monitor to the **robot** and use the built-in CLI:

```
help                → Show commands
mac                 → Show robot's MAC + channel
rn wf               → Walk forward
rn wb               → Walk backward
rn tl / tr          → Turn
rn st               → Stand
rn wv / dn / sw     → Wave / dance / swim
subtrim             → List all trims
st 0 5              → Set servo 0 trim +5
st reset            → Reset all trims
0 90                → Set servo 0 to 90°
all 90              → Set all servos to 90°
```

These commands work alongside ESP-NOW and update the same internal state.

---

## Watching Real-time ESP-NOW Traffic

Controller sends are logged as `OK SENT`. Responses are logged as they arrive.

**Robot-side logging** (Serial Monitor):
- `[ESP-NOW] Motion: forward` — Motion command received
- `[ESP-NOW] Face: happy` — Face command received
- `[ESP-NOW] Trim get` — Trim query received

If the robot prints nothing, ESP-NOW packets aren't being received at all.

---

## Common Pitfalls

| Symptom | Likely Cause | Fix |
|---|---|-----|
| Controller boots, `SET_ROBOT_MAC` works, but PING fails | Robot MAC changed (refreshed) or channel mismatch | Re-copy robot MAC, run `SET_ROBOT_MAC` again; verify channel |
| Robot boots, prints MAC, but controller says "Robot peer not registered" | Controller MAC is all 0xFF (needs to send first message to auto-register) | Send any command (e.g., `PING`) from controller |
| PONG received but >50ms latency | Boards are far apart or WiFi interference | Reduce distance, change to channel 6 or 11 |
| Servo jitter during movements | `motorCurrentDelay` too low | `CONFIG_SET motorCurrentDelay 80` |
| Face doesn't change on `FACE happy` | Face name typo or missing bitmap | Check serial log; valid names are in `face-bitmaps.h` |
| `CMD forward` does nothing | `currentCommand` cleared immediately (motion function returned early) | Check if `pressingCheck()` interrupted; try `CMD rest` and `CMD wave` first |
| Controller resets repeatedly | Power issue (USB cable bad) | Use known-good USB cable / powered hub |

---

## Message Flow Diagram

```
Computer
   │
   ├─ "CMD wave\n" ─────────────────────┐
   │                                     ▼
   │                      Controller (ESP32-C3)
   │                        Parses "wave"
   │                        Builds binary MSG_MOTION_CMD
   │                        msg_id = 42
   │                        esp_now_send() → Robot
   │                                     ├─ Prints "OK SENT"
   │                                     │
   ▼                                     ▼
Robot (ESP32-S3)            ESP-NOW Wireless (1-5 ms)
   │                         Packet arrives
   ▼                        onEspNowRecv()
Parses header               msg_type = 0x01
   │                        msg_id = 42
   │                        → handleMotionCmd()
   │                        → currentCommand = "wave"
   │                        → runWavePose()
   │                        → Sends back ACK
   │                        (msg_type = 0x80,
   │                         orig_msg_id = 42)
   │
   ▼
Controller receives ACK
   │
   ├─ Matches orig_msg_id=42 to pending request
   └─ Prints "OK"
```

---

## Serial Port Tips

- **Baud rate:** 115200
- **USB identification:**
  - Linux: `/dev/ttyUSB0` or `/dev/ttyACM0`
  - macOS: `/dev/cu.usbmodem*`
  - Windows: `COM3` (or higher)
- Many serial terminals can connect (Arduino Serial Monitor, PuTTY, screen, minicom, Python `pyserial`)

**Python quick connect:**
```python
import serial
ser = serial.Serial('/dev/ttyUSB0', 115200, timeout=1)
ser.write(b'PING\n')
print(ser.readline().decode())
# → PONG rtt=...
```

---

## Re-flashing Tips

If you need to re-flash either board:
- **Robot:** Arduino IDE → Board: ESP32S3 Dev → upload `sesame-firmware-espnow.ino`
- **Controller:** Arduino IDE → Board: ESP32C3 Dev → upload `ESP32_C3_Sesame.ino`

After flashing, open Serial Monitor at 115200 baud to see the startup messages.

**Important:** The robot's MAC must be set in the controller's NVS. After re-flashing the controller, you may need to run `SET_ROBOT_MAC` again.

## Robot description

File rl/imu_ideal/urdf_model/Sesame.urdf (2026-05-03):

<?xml version="1.0" encoding="utf-8"?>
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
<robot name="Sesame">
  <link name="base_link">
    <inertial>
      <origin xyz="-0.02315 -0.020775 -0.024241" rpy="0 0 0" />

      <mass value="0.15129" />
      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

    </inertial>
    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
  </link>
  <link name="Link_L2">
    <inertial>
      <origin xyz="-0.0064601 -0.010609 0.017387" rpy="0 0 0" />
      <mass value="0.0053136" />
      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
    </inertial>
    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
  </link>
  <joint name="Joint_L2" type="revolute">
    <origin xyz="0.00069097 -0.046289 -0.0043597" rpy="1.5708 0 -1.5708" />
    <parent link="base_link" />
    <child link="Link_L2" />
    <axis xyz="0 1 0" />
    <limit lower="1.5707963267948966" upper="3.14" effort="0.215" velocity="10.47" />
    <dynamics damping="0.001" friction="0.001" />    
  </joint>
  <link name="Link_L4">
    <inertial>
      <origin xyz="0.0059082 -7.7912E-05 0.009868" rpy="0 0 0" />
      <mass value="0.01181" />
      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
    </inertial>
    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
  </link>
  <joint name="Joint_L4" type="revolute">
    <origin xyz="0 -0.02413 0.03683" rpy="-1.5707963267948966 0 0" />
    <parent link="Link_L2" />
    <child link="Link_L4" />
    <axis xyz="1 0 0" />
    <limit lower="1.5707963267948966" upper="3.1415" effort="0.215" velocity="10.47" />
    <dynamics damping="0.001" friction="0.001" />
  </joint>
  <link name="Link_L1">
    <inertial>
      <origin xyz="-0.006401 -0.010603 -0.017401" rpy="0 0 0" />
      <mass value="0.0053164" />
      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
    </inertial>
    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
  </link>
  <joint name="Joint_L1" type="revolute">
    <origin xyz="-0.047709 -0.046289 -0.0043597" rpy="1.5708 0 1.5708" />
    <parent link="base_link" />
    <child link="Link_L1" />
    <axis xyz="0 1 0" />
    <limit lower="0" upper="1.5707963267948966" effort="0.215" velocity="10.47" />
    <dynamics damping="0.001" friction="0.001" />
  </joint>
  <link name="Link_L3">
    <inertial>
      <origin xyz="0.0046158 -0.00016469 -0.010021" rpy="0 0 0" />
      <mass value="0.011791" />
      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
    </inertial>
    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
  </link>
  <joint name="Joint_L3" type="revolute">
    <origin xyz="0.0014515 -0.02413 -0.036658" rpy="-1.5708 0 0" />
    <parent link="Link_L1" />
    <child link="Link_L3" />
    <axis xyz="1 0 0" />
    <limit lower="0" upper="1.5707963267948966" effort="0.215" velocity="10.47" />
    <dynamics damping="0.001" friction="0.001" />
  </joint>
  <link name="Link_R1">
    <inertial>
      <origin xyz="-0.0064016 -0.010612 0.017415" rpy="0 0 0" />
      <mass value="0.005312" />
      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
    </inertial>
    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
  </link>
  <joint name="Joint_R1" type="revolute">
    <origin xyz="-0.047709 0.0045112 -0.0043597" rpy="1.5708 0 1.5708" />
    <parent link="base_link" />
    <child link="Link_R1" />
    <axis xyz="0 1 0" />
    <limit lower="1.5707963267948966" upper="3.1415" effort="0.215" velocity="10.47" />
    <dynamics damping="0.001" friction="0.001" />
  </joint>
  <link name="Link_R3">
    <inertial>
      <origin xyz="0.00607 -0.00014231 0.0098498" rpy="0 0 0" />
      <mass value="0.01181" />
      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
    </inertial>
    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
  </link>
  <joint name="Joint_R3" type="revolute">
    <origin xyz="0 -0.02413 0.03683" rpy="-1.5707963267948966 0 0" />
    <parent link="Link_R1" />
    <child link="Link_R3" />
    <axis xyz="1 0 0" />
    <limit lower="1.5707963267948966" upper="3.1415" effort="0.215" velocity="10.47" />
    <dynamics damping="0.001" friction="0.001" />
  </joint>
  <link name="Link_R2">
    <inertial>
      <origin xyz="-0.0063919 -0.010646 -0.017449" rpy="0 0 0" />
      <mass value="0.0052948" />
      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
    </inertial>
    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
  </link>
  <joint name="Joint_R2" type="revolute">
    <origin xyz="0.00069097 0.0045112 -0.0043597" rpy="1.5708 0 -1.5708" />
    <parent link="base_link" />
    <child link="Link_R2" />
    <axis xyz="0 1 0" />
    <limit lower="0" upper="1.5707963267948966" effort="0.215" velocity="10.47" />
    <dynamics damping="0.001" friction="0.001" />
  </joint>
  <link name="Link_R4">
    <inertial>
      <origin xyz="0.0045634 -7.1454E-05 -0.0097604" rpy="0 0 0" />
      <mass value="0.011795" />
      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
    </inertial>
    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
  </link>
  <joint name="Joint_R4" type="revolute">
    <origin xyz="0.0015058 -0.02413 -0.036923" rpy="-1.5707963267948966 0 0" />
    <parent link="Link_R2" />
    <child link="Link_R4" />
    <axis xyz="1 0 0" />
    <limit lower="0" upper="1.5707963267948966" effort="0.215" velocity="10.47" />
    <dynamics damping="0.001" friction="0.001" />
  </joint>
</robot>

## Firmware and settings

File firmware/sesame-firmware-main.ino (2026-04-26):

#include <WiFi.h>
#include <WebServer.h>
#include <DNSServer.h>
#include <ESPmDNS.h>
#include <Preferences.h>
#include <Wire.h>
#include <ESP32Servo.h>
#include <Adafruit_GFX.h>
#include <Adafruit_SSD1306.h>
#include "face-bitmaps.h"
#include "movement-sequences.h"
#include "captive-portal.h"

// --- Access Point Configuration ---
// This is the network the Robot will create
#define AP_SSID  "Sesame-Orange-Bot"
#define AP_PASS  "12345678" // Must be at least 8 characters

// --- Station Mode Configuration (Optional) ---
// Set these to connect to your home/office WiFi network
// Leave NETWORK_SSID empty to disable station mode
#define NETWORK_SSID ""  // Your WiFi network name
#define NETWORK_PASS ""  // Your WiFi password
#define ENABLE_NETWORK_MODE false  // Set to true to enable network connection attempts

#define SCREEN_WIDTH 128
#define SCREEN_HEIGHT 64
#define OLED_RESET -1
#define OLED_I2C_ADDR 0x3C

// I2C Pins for Distro Board V2
//#define I2C_SDA 8
//#define I2C_SCL 9

// I2C Pins for Distro Board
#define I2C_SDA 21
#define I2C_SCL 22

// I2C Pins for S2 Mini Board
//#define I2C_SDA 33
//#define I2C_SCL 35


// DNS Server for Captive Portal
DNSServer dnsServer;
const byte DNS_PORT = 53;

Adafruit_SSD1306 display(SCREEN_WIDTH, SCREEN_HEIGHT, &Wire, OLED_RESET);
WebServer server(80);

// Global state for animations
String currentCommand = "";
String currentFaceName = "default";
const unsigned char* const* currentFaceFrames = nullptr;
uint8_t currentFaceFrameCount = 0;
uint8_t currentFaceFrameIndex = 0;
unsigned long lastFaceFrameMs = 0;
int faceFps = 8;
FaceAnimMode currentFaceMode = FACE_ANIM_LOOP;
int8_t faceFrameDirection = 1;
bool faceAnimFinished = false;
int currentFaceFps = 0;
bool idleActive = false;
bool idleBlinkActive = false;
unsigned long nextIdleBlinkMs = 0;
uint8_t idleBlinkRepeatsLeft = 0;

// WiFi Info Scrolling
unsigned long lastInputTime = 0;
bool firstInputReceived = false;
bool showingWifiInfo = false;
int wifiScrollPos = 0;
unsigned long lastWifiScrollMs = 0;
String wifiInfoText = "";

// Network Mode
bool networkConnected = false;
IPAddress networkIP;
String deviceHostname = "sesame-robot";

// Servo Pins for Distro Board
// ======================================================================
// Pin numbers are coorisponding to the ESP32 GPIO pins and may differ based on which board you use.
// If you are using a different board, please adjust the servoPins array accordingly.
// ======================================================================
Servo servos[8];
// Sesame Distro Board V2 Pinout
//const int servoPins[8] = {4, 5, 6, 7, 15, 16, 17, 18};

// Sesame Distro Board Pinout
const int servoPins[8] = {15, 2, 23, 19, 4, 16, 17, 18};

// Lolin S2 Mini Pinout
//const int servoPins[8] = {1, 2, 4, 6, 8, 10, 13, 14};

// Subtrim values for each servo (offset in degrees)
int8_t servoSubtrim[8] = {0, 0, 0, 0, 0, 0, 0, 0};

// Track current target angle for each servo (for real-time trim updates)
int currentServoAngle[8] = {90, 90, 90, 90, 90, 90, 90, 90};

// Set to true to enable saving/loading subtrim values from NVS
#define SAVE_TRIMS false

// NVS for persistent storage
Preferences prefs;

void saveSubtrimToNVS() {
  if (!SAVE_TRIMS) return;
  prefs.begin("sesame", false);
  prefs.putBytes("subtrim", servoSubtrim, sizeof(servoSubtrim));
  prefs.end();
  Serial.println("Subtrim values saved to NVS");
}

void loadSubtrimFromNVS() {
  if (!SAVE_TRIMS) {
    Serial.println("NVS loading disabled, using default subtrim values");
    return;
  }
  prefs.begin("sesame", true);
  size_t len = prefs.getBytesLength("subtrim");
  if (len == sizeof(servoSubtrim)) {
    prefs.getBytes("subtrim", servoSubtrim, sizeof(servoSubtrim));
    Serial.println("Subtrim values loaded from NVS:");
    for (int i = 0; i < 8; i++) {
      Serial.print("Motor "); Serial.print(i); Serial.print(": ");
      if (servoSubtrim[i] >= 0) Serial.print("+");
      Serial.println(servoSubtrim[i]);
    }
  } else {
    Serial.println("No subtrim values in NVS, using defaults");
  }
  prefs.end();
}

void applySubtrimToCurrentPose() {
  for (int i = 0; i < 8; i++) {
    int adjustedAngle = constrain(currentServoAngle[i] + servoSubtrim[i], 0, 180);
    servos[i].write(adjustedAngle);
    delay(5);
  }
}

// Animation constants
int frameDelay = 100;
int walkCycles = 10;
int motorCurrentDelay = 40; // ms delay between motor movements to prevent over-current

void saveSettingsToNVS() {
  prefs.begin("sesame", false);
  prefs.putInt("frameDelay", frameDelay);
  prefs.putInt("walkCycles", walkCycles);
  prefs.putInt("motorCurrentDelay", motorCurrentDelay);
  prefs.putInt("faceFps", faceFps);
  prefs.end();
  Serial.println("Settings saved to NVS");
}

void loadSettingsFromNVS() {
  prefs.begin("sesame", true);
  if (prefs.isKey("frameDelay")) {
    int val = prefs.getInt("frameDelay");
    if (val > 0) frameDelay = val;
  }
  if (prefs.isKey("walkCycles")) {
    int val = prefs.getInt("walkCycles");
    if (val > 0) walkCycles = val;
  }
  if (prefs.isKey("motorCurrentDelay")) {
    int val = prefs.getInt("motorCurrentDelay");
    if (val >= 0) motorCurrentDelay = val;
  }
  if (prefs.isKey("faceFps")) {
    int val = prefs.getInt("faceFps");
    if (val > 0) faceFps = val;
  }
  prefs.end();
  Serial.println("Settings loaded from NVS:");
  Serial.print("  frameDelay: "); Serial.println(frameDelay);
  Serial.print("  walkCycles: "); Serial.println(walkCycles);
  Serial.print("  motorCurrentDelay: "); Serial.println(motorCurrentDelay);
  Serial.print("  faceFps: "); Serial.println(faceFps);
}

struct FaceEntry {
  const char* name;
  const unsigned char* const* frames;
  uint8_t maxFrames;
};

static const uint8_t MAX_FACE_FRAMES = 6;

#define MAKE_FACE_FRAMES(name) \
  const unsigned char* const face_##name##_frames[] = { \
    epd_bitmap_##name, epd_bitmap_##name##_1, epd_bitmap_##name##_2, \
    epd_bitmap_##name##_3, epd_bitmap_##name##_4, epd_bitmap_##name##_5 \
  };

#define X(name) MAKE_FACE_FRAMES(name)
FACE_LIST
#undef X
#undef MAKE_FACE_FRAMES

const FaceEntry faceEntries[] = {
#define X(name) { #name, face_##name##_frames, MAX_FACE_FRAMES },
  FACE_LIST
#undef X
  { "default", face_defualt_frames, MAX_FACE_FRAMES }
};

struct FaceFpsEntry {
  const char* name;
  uint8_t fps;
};

const FaceFpsEntry faceFpsEntries[] = {
  { "walk", 1 },
  { "rest", 1 },
  { "swim", 1 },
  { "dance", 1 },
  { "wave", 1 },
  { "point", 5 },
  { "stand", 1 },
  { "cute", 1 },
  { "pushup", 1 },
  { "freaky", 1 },
  { "bow", 1 },
  { "worm", 1 },
  { "shake", 1 },
  { "shrug", 1 },
  { "dead", 2 },
  { "crab", 1 },
  { "idle", 1 },
  { "idle_blink", 7 },
  { "default", 1 },
  // Conversational faces (manually controlled by Python - no auto-animation)
  { "happy", 1 },
  { "talk_happy", 1 },
  { "sad", 1 },
  { "talk_sad", 1 },
  { "angry", 1 },
  { "talk_angry", 1 },
  { "surprised", 1 },
  { "talk_surprised", 1 },
  { "sleepy", 1 },
  { "talk_sleepy", 1 },
  { "love", 1 },
  { "talk_love", 1 },
  { "excited", 1 },
  { "talk_excited", 1 },
  { "confused", 1 },
  { "talk_confused", 1 },
  { "thinking", 1 },
  { "talk_thinking", 1 },
};


// Prototypes
void setServoAngle(uint8_t channel, int angle);
void updateFaceBitmap(const unsigned char* bitmap);
void setFace(const String& faceName);
void setFaceMode(FaceAnimMode mode);
void setFaceWithMode(const String& faceName, FaceAnimMode mode);
void updateAnimatedFace();
void delayWithFace(unsigned long ms);
void enterIdle();
void exitIdle();
void updateIdleBlink();
int getFaceFpsForName(const String& faceName);
bool pressingCheck(String cmd, int ms);
void handleGetSettings();
void handleSetSettings();
void handleGetStatus();
void handleApiCommand();
void handleGetSubtrim();
void handleSetSubtrim();
void handleResetSubtrim();
void updateWifiInfoScroll();
void recordInput();

void handleRoot() {
  server.send(200, "text/html", index_html);
}

void handleCommandWeb() {
  // We send 200 OK immediately so the web browser doesn't hang waiting for animation to finish
  if (server.hasArg("pose")) {
    currentCommand = server.arg("pose");
    recordInput();
    exitIdle();
    server.send(200, "text/plain", "OK"); 
  } 
  else if (server.hasArg("go")) {
    currentCommand = server.arg("go");
    recordInput();
    exitIdle();
    server.send(200, "text/plain", "OK");
  } 
  else if (server.hasArg("stop")) {
    currentCommand = "";
    recordInput();
    server.send(200, "text/plain", "OK");
  }
  else if (server.hasArg("motor") && server.hasArg("value")) {
    int motorNum = server.arg("motor").toInt();
    int servoIdx = servoNameToIndex(server.arg("motor"));
    int angle = server.arg("value").toInt();
    if (motorNum >= 1 && motorNum <= 8 && angle >= 0 && angle <= 180) {
      setServoAngle(motorNum - 1, angle); // Convert 1-based to 0-based index
      recordInput();
      server.send(200, "text/plain", "OK");
    } else if (servoIdx != -1 && angle >= 0 && angle <= 180) {
      setServoAngle(servoIdx, angle);
      recordInput();
      server.send(200, "text/plain", "OK");
    } else {
      server.send(400, "text/plain", "Invalid motor or angle");
    }
  }
  else {
    server.send(400, "text/plain", "Bad Args");
  }
}

void handleGetSettings() {
  String json = "{";
  json += "\"frameDelay\":" + String(frameDelay) + ",";
  json += "\"walkCycles\":" + String(walkCycles) + ",";
  json += "\"motorCurrentDelay\":" + String(motorCurrentDelay) + ",";
  json += "\"faceFps\":" + String(faceFps);
  json += "}";
  server.send(200, "application/json", json);
}

void handleSetSettings() {
  if (server.hasArg("frameDelay")) frameDelay = server.arg("frameDelay").toInt();
  if (server.hasArg("walkCycles")) walkCycles = server.arg("walkCycles").toInt();
  if (server.hasArg("motorCurrentDelay")) motorCurrentDelay = server.arg("motorCurrentDelay").toInt();
  if (server.hasArg("faceFps")) faceFps = (int)max(1L, server.arg("faceFps").toInt());
  saveSettingsToNVS();
  server.send(200, "text/plain", "OK");
}

// API endpoint for network clients to get robot status
void handleGetStatus() {
  String json = "{";
  json += "\"currentCommand\":\"" + currentCommand + "\",";
  json += "\"currentFace\":\"" + currentFaceName + "\",";
  json += "\"networkConnected\":" + String(networkConnected ? "true" : "false") + ",";
  json += "\"apIP\":\"" + WiFi.softAPIP().toString() + "\"";
  if (networkConnected) {
    json += ",\"networkIP\":\"" + networkIP.toString() + "\"";
  }
  json += "}";
  server.send(200, "application/json", json);
}

// API endpoint for network clients to send commands (JSON-based)
void handleApiCommand() {
  if (server.method() != HTTP_POST) {
    server.send(405, "application/json", "{\"error\":\"Method not allowed\"}");
    return;
  }
  
  String body = server.arg("plain");
  
  Serial.println("API Command received:");
  Serial.println(body);
  
  // Check for face-only command (no movement)
  int faceOnlyStart = body.indexOf("\"face\":\"");
  if (faceOnlyStart == -1) {
    faceOnlyStart = body.indexOf("\"face\": \"");
  }
  
  // If we have a face but no command field, it's face-only
  bool faceOnly = (faceOnlyStart > 0 && body.indexOf("\"command\":") == -1 && body.indexOf("\"command\": ") == -1);
  
  String command = "";
  String face = "";
  
  // Parse face
  if (faceOnlyStart > 0) {
    faceOnlyStart = body.indexOf("\"", faceOnlyStart + 6) + 1;
    int faceEnd = body.indexOf("\"", faceOnlyStart);
    if (faceEnd > faceOnlyStart) {
      face = body.substring(faceOnlyStart, faceEnd);
      Serial.print("Parsed face: ");
      Serial.println(face);
    }
  }
  
  // Parse command (if not face-only)
  if (!faceOnly) {
    int cmdStart = body.indexOf("\"command\":\"");
    if (cmdStart == -1) {
      cmdStart = body.indexOf("\"command\": \"");
    }
    
    if (cmdStart == -1) {
      Serial.println("Error: command field not found");
      server.send(400, "application/json", "{\"error\":\"Missing command field\"}");
      return;
    }
    
    cmdStart = body.indexOf("\"", cmdStart + 10) + 1;
    int cmdEnd = body.indexOf("\"", cmdStart);
    
    if (cmdEnd <= cmdStart) {
      Serial.println("Error: invalid command format");
      server.send(400, "application/json", "{\"error\":\"Invalid command format\"}");
      return;
    }
    
    command = body.substring(cmdStart, cmdEnd);
    Serial.print("Parsed command: ");
    Serial.println(command);
  }
  
  // Set face if provided
  if (face.length() > 0) {
    setFace(face);
  }
  
  // If face-only, just acknowledge
  if (faceOnly) {
    recordInput();
    server.send(200, "application/json", "{\"status\":\"ok\",\"message\":\"Face updated\"}");
    return;
  }
  
  // Execute command
  if (command == "stop") {
    currentCommand = "";
    recordInput();
    server.send(200, "application/json", "{\"status\":\"ok\",\"message\":\"Command stopped\"}");
  } else {
    currentCommand = command;
    recordInput();
    exitIdle();
    server.send(200, "application/json", "{\"status\":\"ok\",\"message\":\"Command executed\"}");
  }
}
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
void loop() {
  // Process DNS requests for captive portal
  dnsServer.processNextRequest();
  
  server.handleClient();
  updateAnimatedFace();
  updateIdleBlink();
  updateWifiInfoScroll();

  if (currentCommand != "") {
    String cmd = currentCommand;
    if (cmd == "forward") runWalkPose();
    else if (cmd == "backward") runWalkBackward();
    else if (cmd == "left") runTurnLeft();
    else if (cmd == "right") runTurnRight();
    else if (cmd == "rest") { runRestPose(); if (currentCommand == "rest") currentCommand = ""; }
    else if (cmd == "stand") { runStandPose(1); if (currentCommand == "stand") currentCommand = ""; }
    else if (cmd == "wave") runWavePose();
    else if (cmd == "dance") runDancePose();
    else if (cmd == "swim") runSwimPose();
    else if (cmd == "point") runPointPose();
    else if (cmd == "pushup") runPushupPose();
    else if (cmd == "bow") runBowPose();
    else if (cmd == "cute") runCutePose();
    else if (cmd == "freaky") runFreakyPose();
    else if (cmd == "worm") runWormPose();
    else if (cmd == "shake") runShakePose();
    else if (cmd == "shrug") runShrugPose();
    else if (cmd == "dead") runDeadPose();
    else if (cmd == "crab") runCrabPose();
  }
  
  // Serial CLI for debugging (can be used to diagnose servo position issues and wiring)
  if (Serial.available()) {
    static char command_buffer[32];
    static byte buffer_pos = 0;
    char c = Serial.read();
    if (c == '\n' || c == '\r') {
      if (buffer_pos > 0) {
        command_buffer[buffer_pos] = '\0';
        int motorNum, angle;
        recordInput();
        if(strcmp(command_buffer, "run walk") == 0 || strcmp(command_buffer, "rn wf") == 0) { currentCommand = "forward"; runWalkPose(); currentCommand = ""; }
        else if(strcmp(command_buffer, "rn wb") == 0) { currentCommand = "backward"; runWalkBackward(); currentCommand = ""; }
        else if(strcmp(command_buffer, "rn tl") == 0) { currentCommand = "left"; runTurnLeft(); currentCommand = ""; }
        else if(strcmp(command_buffer, "rn tr") == 0) { currentCommand = "right"; runTurnRight(); currentCommand = ""; }
        else if(strcmp(command_buffer, "run rest") == 0 || strcmp(command_buffer, "rn rs") == 0) runRestPose();
        else if(strcmp(command_buffer, "run stand") == 0 || strcmp(command_buffer, "rn st") == 0) runStandPose(1);
        else if(strcmp(command_buffer, "rn wv") == 0) { currentCommand = "wave"; runWavePose(); }
        else if(strcmp(command_buffer, "rn dn") == 0) { currentCommand = "dance"; runDancePose(); }
        else if(strcmp(command_buffer, "rn sw") == 0) { currentCommand = "swim"; runSwimPose(); }
        else if(strcmp(command_buffer, "rn pt") == 0) { currentCommand = "point"; runPointPose(); }
        else if(strcmp(command_buffer, "rn pu") == 0) { currentCommand = "pushup"; runPushupPose(); }
        else if(strcmp(command_buffer, "rn bw") == 0) { currentCommand = "bow"; runBowPose(); }
        else if(strcmp(command_buffer, "rn ct") == 0) { currentCommand = "cute"; runCutePose(); }
        else if(strcmp(command_buffer, "rn fk") == 0) { currentCommand = "freaky"; runFreakyPose(); }
        else if(strcmp(command_buffer, "rn wm") == 0) { currentCommand = "worm"; runWormPose(); }
        else if(strcmp(command_buffer, "rn sk") == 0) { currentCommand = "shake"; runShakePose(); }
        else if(strcmp(command_buffer, "rn sg") == 0) { currentCommand = "shrug"; runShrugPose(); }
        else if(strcmp(command_buffer, "rn dd") == 0) { currentCommand = "dead"; runDeadPose(); }
        else if(strcmp(command_buffer, "rn cb") == 0) { currentCommand = "crab"; runCrabPose(); }
        else if (strcmp(command_buffer, "subtrim") == 0 || strcmp(command_buffer, "st") == 0) {
          Serial.println("Subtrim values:");
          for (int i = 0; i < 8; i++) {
            Serial.print("Motor "); Serial.print(i); Serial.print(": ");
            if (servoSubtrim[i] >= 0) Serial.print("+");
            Serial.println(servoSubtrim[i]);
          }
        }
        else if (strcmp(command_buffer, "subtrim save") == 0 || strcmp(command_buffer, "st save") == 0) {
          saveSubtrimToNVS();
          Serial.println("Subtrim values saved to NVS");
        }
        else if (strncmp(command_buffer, "subtrim reset", 13) == 0 || strncmp(command_buffer, "st reset", 8) == 0) {
          for (int i = 0; i < 8; i++) servoSubtrim[i] = 0;
          applySubtrimToCurrentPose();
          saveSubtrimToNVS();
          Serial.println("All subtrim values reset to 0 and saved to NVS");
        }
        else if (strcmp(command_buffer, "settings reset") == 0) {
          frameDelay = 100;
          walkCycles = 10;
          motorCurrentDelay = 40;
          faceFps = 8;
          saveSettingsToNVS();
          Serial.println("Settings reset to defaults and saved to NVS");
        }
        else if (strncmp(command_buffer, "subtrim ", 8) == 0 || strncmp(command_buffer, "st ", 3) == 0) {
          const char* params = (command_buffer[1] == 't') ? command_buffer + 3 : command_buffer + 8;
          int trimMotor, trimValue;
          if (sscanf(params, "%d %d", &trimMotor, &trimValue) == 2) {
            if (trimMotor >= 0 && trimMotor < 8) {
              if (trimValue >= -90 && trimValue <= 90) {
                servoSubtrim[trimMotor] = trimValue;
                applySubtrimToCurrentPose();
                saveSubtrimToNVS();
                Serial.print("Motor "); Serial.print(trimMotor); Serial.print(" subtrim set to ");
                if (trimValue >= 0) Serial.print("+");
                Serial.println(trimValue);
              } else {
                Serial.println("Subtrim value must be between -90 and +90");
              }
            } else {
              Serial.println("Invalid motor number (0-7)");
            }
          }
        }
        else if (strncmp(command_buffer, "all ", 4) == 0) {
             if (sscanf(command_buffer + 4, "%d", &angle) == 1) {
                 for (int i = 0; i < 8; i++) setServoAngle(i, angle);
                 Serial.print("All servos set to "); Serial.println(angle);
             }
        }
        else if (sscanf(command_buffer, "%d %d", &motorNum, &angle) == 2) {
             if (motorNum >= 0 && motorNum < 8) {
                 setServoAngle(motorNum, angle);
                 Serial.print("Servo "); Serial.print(motorNum); Serial.print(" set to "); Serial.println(angle);
             } else {
                 Serial.println("Invalid motor number (0-7)");
             }
        }
        buffer_pos = 0;
      }
    } else if (buffer_pos < sizeof(command_buffer) - 1) {
      command_buffer[buffer_pos++] = c;
    }
  }
}

// Function to update the robot's face
void updateFaceBitmap(const unsigned char* bitmap) {
  display.clearDisplay();
  display.drawBitmap(0, 0, bitmap, 128, 64, SSD1306_WHITE);
  display.display();
}

uint8_t countFrames(const unsigned char* const* frames, uint8_t maxFrames) {
  if (frames == nullptr || frames[0] == nullptr) return 0;
  uint8_t count = 0;
  for (uint8_t i = 0; i < maxFrames; i++) {
    if (frames[i] == nullptr) break;
    count++;
  }
  return count;
}

void setFace(const String& faceName) {
  if (faceName == currentFaceName && currentFaceFrames != nullptr) return;

  currentFaceName = faceName;
  currentFaceFrameIndex = 0;
  lastFaceFrameMs = 0;
  faceFrameDirection = 1;
  faceAnimFinished = false;
  currentFaceFps = getFaceFpsForName(faceName);

  currentFaceFrames = face_defualt_frames;
  currentFaceFrameCount = countFrames(face_defualt_frames, MAX_FACE_FRAMES);

  for (size_t i = 0; i < (sizeof(faceEntries) / sizeof(faceEntries[0])); i++) {
    if (faceName.equalsIgnoreCase(faceEntries[i].name)) {
      currentFaceFrames = faceEntries[i].frames;
      currentFaceFrameCount = countFrames(faceEntries[i].frames, faceEntries[i].maxFrames);
      break;
    }
  }

  if (currentFaceFrameCount == 0) {
    currentFaceFrames = face_defualt_frames;
    currentFaceFrameCount = countFrames(face_defualt_frames, MAX_FACE_FRAMES);
    currentFaceName = "default";
    currentFaceFps = getFaceFpsForName(currentFaceName);
  }

  if (currentFaceFrameCount > 0 && currentFaceFrames[0] != nullptr) {
    updateFaceBitmap(currentFaceFrames[0]);
  }
}

void setFaceMode(FaceAnimMode mode) {
  currentFaceMode = mode;
  faceFrameDirection = 1;
  faceAnimFinished = false;
}

void setFaceWithMode(const String& faceName, FaceAnimMode mode) {
  setFaceMode(mode);
  setFace(faceName);
}

int getFaceFpsForName(const String& faceName) {
  for (size_t i = 0; i < (sizeof(faceFpsEntries) / sizeof(faceFpsEntries[0])); i++) {
    if (faceName.equalsIgnoreCase(faceFpsEntries[i].name)) {
      return faceFpsEntries[i].fps;
    }
  }
  return faceFps;
}
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

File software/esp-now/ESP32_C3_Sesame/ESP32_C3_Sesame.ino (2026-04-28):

/*
 * ESP32_C3_Sesame - ESP-NOW Controller for Sesame Robot
 * 
 * Runs on an ESP32-C3 Mini connected to a computer or Raspberry Pi via USB serial.
 * Bridges text serial commands to ESP-NOW binary protocol for controlling the robot.
 *
 * Serial Protocol (115200 baud, newline terminated):
 *   CMD <motion>           - Play motion (forward, backward, left, right, rest, stand,
 *                            wave, dance, swim, point, pushup, bow, cute, freaky,
 *                            worm, shake, shrug, dead, crab)
 *   STOP                   - Stop current motion
 *   FACE <name>            - Set face expression (happy, sad, idle, walk, etc.)
 *   SERVO <ch> <angle>     - Set servo channel (0-7) to angle (0-180)
 *   SERVO_ALL <angle>      - Set all servos to same angle
 *   TRIM_SET <ch> <val>    - Set subtrim for channel (0-7), value (-90 to 90)
 *   TRIM_GET               - Get all subtrim values
 *   TRIM_RESET             - Reset all subtrims to 0
 *   CONFIG_SET <key> <val> - Set config (frameDelay, walkCycles, motorCurrentDelay, faceFps)
 *   CONFIG_GET             - Get all config values
 *   STATUS                 - Get robot status (current command + face)
 *   PING                   - Measure round-trip latency
 *   MAC                    - Show this controller's MAC address
 *   CHANNEL <n>            - Set ESP-NOW channel (1-13), requires restart
 *   HELP                   - Show available commands
 *
 * Wiring: USB only (no GPIO needed)
 * Board: ESP32-C3 Mini (or any ESP32-C3 board)
 */

#include <esp_now.h>
#include <WiFi.h>
#include <esp_wifi.h>
#include <Preferences.h>
#include "../espnow-protocol.h"

// ============================================================================
// Configuration
// ============================================================================

// MAC Address of the Robot (ESP32-S3)
// ** UPDATE THIS with the MAC printed by the robot firmware at boot **
uint8_t robotAddress[] = {0xFF, 0xFF, 0xFF, 0xFF, 0xFF, 0xFF};

// Response timeout (ms)
#define RESPONSE_TIMEOUT_MS  2000

// ============================================================================
// State
// ============================================================================
static uint8_t msgIdCounter = 0;
static bool peerRegistered = false;
static Preferences prefs;

// Pending request tracking
static uint8_t pendingMsgId = 0;
static uint8_t pendingMsgType = 0;
static unsigned long pendingSentTime = 0;
static bool pendingResponse = false;

// Ping tracking
static uint32_t pingSentTimestamp_us = 0;

// ESP-NOW channel (persisted)
static uint8_t espnowChannel = ESPNOW_CHANNEL;

// Serial input buffer
#define SERIAL_BUF_SIZE 128
static char serialBuf[SERIAL_BUF_SIZE];
static uint8_t serialBufPos = 0;

// ============================================================================
// Forward declarations
// ============================================================================
void processSerialCommand(const char* line);
void sendMotionCmd(const char* cmd);
void sendFaceCmd(const char* face);
void sendStopCmd();
void sendServoSet(uint8_t channel, uint8_t angle);
void sendServoAll(uint8_t angle);
void sendTrimSet(uint8_t channel, int8_t value);
void sendTrimGet();
void sendTrimReset();
void sendConfigSet(const char* key, int16_t value);
void sendConfigGet();
void sendStatusGet();
void sendPing();
bool sendEspNow(const uint8_t* data, size_t len);
uint8_t nextMsgId();
uint8_t configKeyFromString(const char* key);
void printHelp();

// ============================================================================
// ESP-NOW Callbacks
// ============================================================================

void OnDataSent(const uint8_t *mac_addr, esp_now_send_status_t status) {
  if (status != ESP_NOW_SEND_SUCCESS) {
    Serial.println("ERR ESP-NOW send failed");
    pendingResponse = false;
  }
}

void OnDataRecv(const esp_now_recv_info_t *recv_info, const uint8_t *data, int data_len) {
  if (data_len < (int)sizeof(sesame_msg_header_t)) return;

  const sesame_msg_header_t* hdr = (const sesame_msg_header_t*)data;

  switch (hdr->msg_type) {
    case MSG_ACK: {
      if (data_len >= (int)sizeof(sesame_ack_t)) {
        const sesame_ack_t* ack = (const sesame_ack_t*)data;
        if (ack->status == ACK_OK) {
          Serial.println("OK");
        } else if (ack->status == ACK_ERR_UNKNOWN) {
          Serial.println("ERR Unknown command on robot");
        } else if (ack->status == ACK_ERR_INVALID) {
          Serial.println("ERR Invalid parameters");
        } else {
          Serial.println("ERR Robot error");
        }
        if (pendingResponse && ack->orig_msg_id == pendingMsgId) {
          pendingResponse = false;
        }
      }
      break;
    }

    case MSG_TRIM_DATA: {
      if (data_len >= (int)sizeof(sesame_trim_data_t)) {
        const sesame_trim_data_t* td = (const sesame_trim_data_t*)data;
        Serial.printf("TRIM %d %d %d %d %d %d %d %d\n",
          td->subtrim[0], td->subtrim[1], td->subtrim[2], td->subtrim[3],
          td->subtrim[4], td->subtrim[5], td->subtrim[6], td->subtrim[7]);
        pendingResponse = false;
      }
      break;
    }

    case MSG_CONFIG_DATA: {
      if (data_len >= (int)sizeof(sesame_config_data_t)) {
        const sesame_config_data_t* cd = (const sesame_config_data_t*)data;
        Serial.printf("CONFIG frameDelay=%d walkCycles=%d motorCurrentDelay=%d faceFps=%d sensorMode=%d sensorRate=%d\n",
          cd->frameDelay, cd->walkCycles, cd->motorCurrentDelay, cd->faceFps,
          cd->sensorMode, cd->sensorRate);
        pendingResponse = false;
      }
      break;
    }

    case MSG_STATUS_DATA: {
      if (data_len >= (int)sizeof(sesame_status_data_t)) {
        const sesame_status_data_t* sd = (const sesame_status_data_t*)data;
        Serial.printf("STATUS cmd=%s face=%s\n", sd->currentCommand, sd->currentFace);
        pendingResponse = false;
      }
      break;
    }

    case MSG_PONG: {
      if (data_len >= (int)sizeof(sesame_pong_t)) {
        const sesame_pong_t* pong = (const sesame_pong_t*)data;
        uint32_t now_us = micros();
        uint32_t rtt_us = now_us - pong->orig_timestamp_us;
        Serial.printf("PONG rtt=%.2fms\n", rtt_us / 1000.0f);
        pendingResponse = false;
      }
      break;
    }

    case MSG_SENSOR_DATA: {
      if (data_len >= (int)sizeof(sesame_sensor_data_t)) {
        const sesame_sensor_data_t* sd = (const sesame_sensor_data_t*)data;
        Serial.printf("SENSOR mode=%d ax=%.3f ay=%.3f az=%.3f gx=%.3f gy=%.3f gz=%.3f mx=%.3f my=%.3f mz=%.3f roll=%.3f pitch=%.3f yaw=%.3f\n",
          sd->mode, sd->ax, sd->ay, sd->az, sd->gx, sd->gy, sd->gz,
          sd->mx, sd->my, sd->mz, sd->roll, sd->pitch, sd->yaw);
      }
      break;
    }

    default:
      Serial.printf("ERR Unknown response type 0x%02X\n", hdr->msg_type);
      break;
  }
}
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

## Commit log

2025-12-02 Revise README for ESP32-based Sesame project
    Updated project description and hardware requirements to reflect the use of ESP32 and PCA9685. Revised features and added a warning about the repository's construction status.
2026-01-08 Revamp README with badges and improved build instructions
    Added project badges for license, microcontroller, firmware, IDE, and GitHub stats. Reorganized and clarified build instructions, including step-by-step getting started guide, links to BOM, printing,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
2026-01-09 Revise hardware README with detailed build guide
    Expanded the hardware/README.md to include a directory guide, build path options, step-by-step getting started instructions, and links to supporting documents. This update clarifies the hardware stac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
2026-01-09 Revamp build guide
    Expanded the Sesame Robot build guide with a clear phased workflow, detailed checklists, and step-by-step instructions for each assembly stage. Added tables, tips, warnings, and troubleshooting advice to improve clarity and reduce common errors. The guide now covers parts gathering, wiring, hardware pre-assembly, main assembly, calibration, and final firmware flashing, making the build process more organized and beginner-friendly.
2026-01-09 Expand wiring guide
    Added a section describing two wiring strategies (S2 Mini/hand wiring and Sesame Distro Board/ESP32-DevKitC-32E) to help users choose based on their needs. Included references to wiring diagrams for both methods and clarified instructions. Replaced PCBway sponsorship details with a link to the hardware documentation for more information.
2026-01-21 Document 2× 10440 Li-ion + AAA holder battery option
    Updated build, wiring, and BOM documentation to include details and recommendations for using 2× 10440 Li-ion cells in a 2× AAA holder as a battery option. Added notes on fit, wiring, charging, and sourcing to guide users considering this alternative.
    https://github.com/dorianborian/sesame-robot/issues/3
2026-01-22 Add Correct Top cover file for enclosed cat
    https://github.com/dorianborian/sesame-robot/issues/12
    [sesame-top-cover-enclosed-cat.stl]
2026-01-23 Add detailed firmware flashing instructions to README
    Expanded the README with step-by-step instructions for flashing the firmware, including prerequisites, board setup, configuration, upload process, and troubleshooting tips.
2026-01-29 Initial 2 leg design.
    [sesame leg proto shock.stl, sesame leg slipper tpu.stl]
2026-01-29 Added stl object.
    [foot-joint-l4-shock-hole.stl]
2026-02-15 Added initial test bench for ESP32 fast protocol
2026-04-24 Add servo subtrim NVS persistence and upstream merge
    - Add NVS (Non-Volatile Storage) support for servo subtrim values
    * Load subtrim values from NVS on boot (namespace: 'sesame')
    * Save subtrim values to NVS on every change (web UI, serial CLI, reset)
    * Uses Preferences.h with putBytes/getBytes for compact 8-byte storage
    - Merge upstream/main changes:
    * Network mode (AP+STA) with mDNS support
    * JSON API endpoints: /api/status, /api/command
    * Conversational faces (happy, sad, angry, surprised, etc.)
    * Distro Board V2 pinout support
    * servoNameToIndex() function for named servo control
    - Keep existing subtrim web UI feature:
    * Trims section with +/- buttons for L1-L4, R1-R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
    [sesame-firmware-main.ino]
2026-04-24 Apply subtrim changes to servos in real-time
    - Track current target angle for each servo in currentServoAngle[]
    - setServoAngle() now records the target angle before applying subtrim
    - applySubtrimToCurrentPose() re-applies all 8 servos with updated subtrim offsets
    - Called immediately after any subtrim change (web UI +/- buttons, reset, serial CLI)
    - 5ms delay between each servo to prevent power surge
    - User now sees immediate servo movement when adjusting trims in the web UI
    [sesame-firmware-main.ino]
2026-04-24 Improve captive portal UI: move Trims to full-screen panel, compact CSS
    - Move Trims section from inline to full-screen overlay panel (like Settings/Motor Control)
    - Add Trims button in System section under Settings button
    - Compact CSS rules to reduce whitespace without changing functionality
    - Add openTrims()/closeTrims() JS functions
    - Trim panel loads current values on open via loadSubtrim()
2026-04-24 Ensure trim +/- render as buttons, not scrollers
    - Add -webkit-appearance:none and appearance:none to trim buttons
    - Add touch-action:manipulation to prevent scroll interference
    - Add -webkit-tap-highlight-color:transparent for clean tap response
    - Increase button size to 40x40px for better touch targets
    - Use display:inline-flex with center alignment for proper button rendering
2026-04-24 Update firmware README with servo trims documentation
    - Add Servo Calibration & Trims section with usage instructions
    - Document trim API endpoints (/getSubtrim, /setSubtrim, /resetSubtrim)
    - Add SAVE_TRIMS NVS persistence configuration docs
    - Document serial CLI subtrim commands
    - Add Web Control Interface subsection describing trim UI features
    - Update Table of Contents with new Trims section
    - Update API reference with trim endpoints in communication stack docs
2026-04-26 Removed unused motor speed drop down
2026-04-26 Store animation settings in NVS
    - Add saveSettingsToNVS() and loadSettingsFromNVS() functions
    - Persist frameDelay, walkCycles, motorCurrentDelay, and faceFps
    - Load settings from NVS at startup
    - Save settings when updated via SetSettings endpoint
2026-04-26 Fix compilation error: move NVS settings functions after variable declarations
    [sesame-firmware-main.ino]
2026-04-26 Improve NVS settings handling with validation and reset command
    - Add range validation when loading settings from NVS to prevent invalid values
    - Add "settings reset" serial CLI command to restore default settings
    - Protect against corrupted or out-of-range persisted values
    [sesame-firmware-main.ino]
2026-04-27 feat: Add ESP-NOW protocol and controller implementation
    - Add shared protocol header (espnow-protocol.h) with 12 command and 6 response message types
    - Implement controller firmware (ESP32_C3_Sesame.ino) as USB serial ↔ ESP-NOW bridge
    - Implement robot firmware (sesame-firmware-espnow.ino) with WiFi stripped, pure ESP-NOW
    - Add comprehensive documentation: command reference, protocol spec, quick start, Python examples
    - Add debug quick-reference guide with troubleshooting flowchart
    - Update top-level and per-directory READMEs with ESP-NOW feature overview and getting started
2026-04-28 feat: Add MPU6050 sensor support via I2C
    - Add Adafruit MPU6050 library integration to robot firmware
    - New sensor data streaming via ESP-NOW (accel, gyro, rpy angles)
    - Configurable sensor mode (off/accel/gyro/magneto/rpy) and update rate
    - Sensor data sent as MSG_SENSOR_DATA (0x85) binary messages
    - Controller displays full sensor data including roll/pitch/yaw
    - NVS persistence for sensor settings
    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
2026-05-01 feat: improve sim-to-real fidelity for MG90S servo hardware
    Model three concrete hardware limitations of the Sesame robot so the
    trained policy is deployable on the ESP32 without further adaptation:
    - Actuator command delay (40 ms / 8 physics steps) matching firmware
    motorCurrentDelay; randomisable to 80 ms to cover sequential 8-servo
    dispatch spread. DcMotorActuatorCfg torque-speed branch included but
    gated off by default (requires retrain from scratch).
    - joint_pos observation patched to delayed (2–4 control steps) + Gaussian
    noise (0.05 rad) on the actor only; critic retains ground-truth for
    stable value estimation.
    - joint_vel and base_lin_vel dropped from both groups: no ve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
2026-05-03 feat: add core RL training and visualization files to sim2real branch
    - Add play.py for policy visualization
    - Add train.py for PPO training runs
    - Add validate.py for sanity checking
    - Add Sesame URDF model and mesh files
    - Add environment configuration files (config.py, env_cfg.py, sesame_robot.py) to tracking
    - Exclude __pycache__ directories from version control
    [Link_L1.STL, Link_L2.STL, Link_L3.STL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]
2026-05-03 docs: enhance README with detailed simulation timing explanation
    - Added section explaining simulation timesteps & control frequency
    - Documented physics timestep (5ms), decimation (4), and control frequency (50Hz)
    - Explained relationship: policy runs at 50Hz (20ms per control step)
    - Clarified actuator delay mapping: 40ms hardware delay = 8 physics steps
    - Referenced verification in config.py, env_cfg.py, and validate.py
2026-05-09 feat: add firmware sequence replay and improve training stability
    - sequences.py: translates all 19 firmware gait sequences from
    movement-sequences.h into MuJoCo simulation actions using the same
    env/viewer stack as validate.py; includes motor ID → URDF joint
    mapping, Keyframe model, _Builder helper, SequencePlayer policy
    - README.md: full Firmware Sequence Replay section with mapping table,
    angle conversion formula, sequence catalogue, CLI examples, and
    architecture notes; layout tree updated
    - env_cfg.py: override push_robot velocity_range to zero vertical
    component, preventing ground penetration / NaN physics on Sesame's
    6 cm ground clearance
    - config.py: re-tune reward we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
2026-05-09 feat: add web UI sequence selector and update docs
    - sequences.py: add Sequence dropdown to Viser web UI — selecting a
    sequence takes effect immediately without restarting; uses a shared
    viser.ViserServer so the dropdown appears above the viewer's own tabs
    in one panel; SequencePlayer gains load_sequence() + threading.Lock
    so the Viser callback thread and sim-loop thread cannot race
    - README.md: document web UI dropdown, runtime switching, threading
    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
2026-05-09 fix: reset env and transition through rest on sequence switch
    Prevents the robot from flipping when changing sequences mid-motion:
    - Always prepend rest keyframes before any new sequence so the robot
    returns to a neutral pose before executing the next motion
    - Call viewer.request_reset() on sequence switch to clear accumulated
    velocity and tilt before starting fresh (viewer created before the
    dropdown callback so request_reset() is accessible via closure)
    - Default initial sequence is now rest instead of (all), giving the
    robot a stable grounded starting pose
    - README updated to document the two-step switch behaviour
2026-05-09 feat: smaller actor network and realistic lin vel observation
    - Actor hidden dims (256,512,256,128) → (64,128,64): ~19k params, ~75 KB,
    fits ESP32 internal SRAM without PSRAM. Critic kept large (training-only).
    - Enable OBS_BASE_LIN_VEL_ENABLED: velocity estimated on hardware by
    integrating MPU6050 accelerometer after DMP gravity removal. Actor sees
    noisy version (IMU_LIN_VEL_NOISE_STD=0.2 m/s) modelling integration drift;
    critic retains ground-truth (privileged architecture).
    - README: add observation-space table, actor/critic size table, update
    sim-to-real flag descriptions, tick off two roadmap items.
2026-05-09 feat: add run.sh training manager script
    start/stop/status/logs/clean commands for managing nohup training
    and TensorBoard as background processes. PIDs saved to .train.pid
    and .tb.pid; status shows checkpoint count and last training output.
2026-05-10 fix: reset env and transition through rest on sequence switch
    Delay yaw introduction to iteration 3500 (was 1500) and cap max yaw
    at ±0.5 rad/s (was ±1.0). MG90S legs cannot reliably generate the
    torque needed for fast yaw, so training with ±1.0 caused the policy
    to approximate yaw via body tilt, which bled into straight-walking.
    Lateral strafe now introduced at iteration 2000 (was 1000) to give
    more time for stable forward locomotion before adding new axes.
2026-05-10 fix: correct URDF forward direction with 180° Z rotation
    The Solidworks→URDF export placed body +X (the velocity command "forward"
    axis) pointing toward the visual rear of the model. Add BASE_INIT_ROT =
    (w=0, x=0, y=0, z=1) — a 180° Z quaternion — so the purple velocity arrow
    and the visual front of Sesame now agree. Requires retraining from scratch
    (already underway) since spawn orientation changed.
2026-05-10 fix: enable obs_normalization on critic to prevent value loss NaN
    The critic (256,512,256,128) with no input normalization repeatedly
    overflows float32 when reward magnitudes are large, producing NaN value
    loss that corrupts both networks via the shared optimizer backward pass.
    Enabling obs_normalization on the critic only (running mean/std layer)
    keeps its inputs bounded without affecting the actor — the actor stays
    False since it must export cleanly to ONNX for ESP32 inference.
2026-05-10 fix: switch from adaptive to fixed LR schedule to prevent NaN crashes
    Root cause of recurring NaN crashes: the adaptive LR schedule drove LR
    to near-zero when KL exceeded desired_kl. With LR≈0 the value function
    stopped learning, but the entropy gradient kept drifting the policy std
    upward. Growing std → occasional large actions → value targets diverged
    from stale predictions → value loss → inf → when LR partially recovered,
    inf×lr corrupted both networks.
    Switch to fixed LR=3e-4 (standard PPO value). This guarantees both
    actor and critic always receive consistent gradient updates and prevents
    the LR-collapse → value-diverge → NaN cascade entirely.
2026-05-11 fix: increase actor size and reduce lin_vel noise to enable locomotion
    Actor (64,128,64)→(128,128,64): 19k→45k params; small network learned to
    bounce in place rather than coordinate 8-DOF gait. 45k params fits 4MB PSRAM.
    IMU_LIN_VEL_NOISE_STD 0.2→0.05 m/s: 0.2 m/s was 40% of the ±0.5 m/s command
    range (SNR≈1.25), causing the policy to ignore velocity feedback entirely.
    0.05 m/s gives SNR≈10, restoring meaningful velocity tracking signal.

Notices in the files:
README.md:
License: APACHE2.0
